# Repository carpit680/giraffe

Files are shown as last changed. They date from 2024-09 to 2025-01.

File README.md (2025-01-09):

<!-- @format -->

# _giraffe: a low-cost robotic manipulator_ 🦒

```text
                                   __             ___  ___
                            .-----|__.----.---.-.'  _.'  _.-----.
                            |  _  |  |   _|  _  |   _|   _|  -__|
                            |___  |__|__| |___._|__| |__| |_____|
                            |_____|

                               Why should fun be out of reach?
```

A [Koch v1.1](https://github.com/jess-moss/koch-v1-1) inspired even more cost-effective, ROS2-compatible, Open-Source robotic manipulator designed to lower the barriers of entry for Embodied AI and whatever else your robotic dreams may be.

To achieve these outcomes, we implemented the following significant changes:

## **Servo Selection**

We redesigned the arm around cost-efficient Waveshare servos replacing Dynamixel servos, effectively doubling the torque while reducing costs.

## **Design Enhancements**

- Adjusted the base design to transfer the radial load from the base motor to the supporting structure, reducing motor stress.
- Relocated the servo driver closer to the base for cleaner design.
- The servo mounts were redesigned to utilize the fasteners provided with the servos, minimizing the required assembly components to just the servos, 3D-printed parts, and a screwdriver.

- **[Teleop Tongs](https://github.com/carpit680/teleop_tongs) Integration**

  We integrated support for Teleop Tongs, another open-source project we built on top of [Dex Teleop](https://github.com/hello-robot/stretch_dex_teleop) (for the [Stretch 3](https://hello-robot.com/stretch-3-product) mobile manipulator by [Hello Robot](https://hello-robot.com/)), designed for teleoperating general-purpose robotic manipulators. This system features a 3D-printed tongs assembly equipped with multiple fiducial markers, serving as a stand-in for the end effector. This design enables intuitive and accessible control of the robotic arm.

  The motivation behind this integration was to offer a cost-effective, and user-friendly alternative to a leader & follower arm setup. By using Teleop Tongs, operators can manipulate the robotic arm naturally, simplifying teleoperation for applications in education, research, or DIY robotics projects.

---

## Assembly Instructions

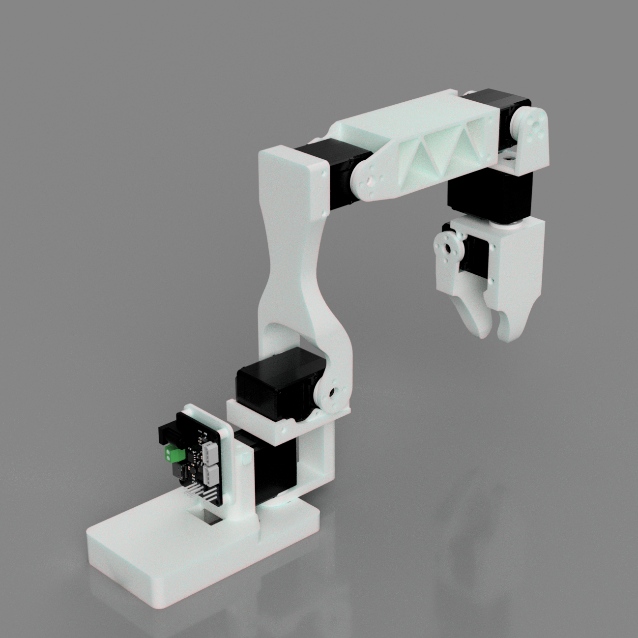
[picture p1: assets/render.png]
Image of Giraffe Rendered


### Sourcing Parts

Order the off the shelf parts for the arm using the links below.

| Part | Amount | Unit Cost (India)| Total Cost (India)| Buying Link (India) |
| --- | --- | --- | --- | --- |
| WaveShare ST3215 30Kg | 6 | ₹1,949.00 | ₹11,694.00 | [Robu.in](https://robu.in/product/waveshare-30kg-serial-bus-servo/) |
| Waveshare Serial Bus Servo Driver Board | 1 | ₹499.00 | ₹499.00 | [Robu.in](https://robu.in/product/waveshare-serial-bus-servo-driver-board-integrates-servo-power-supply-and-control-circuit-applicable-for-st-sc-series-serial-bus-servos/) |
| 12V 20A Power Supply | 1 | ₹895.00 | ₹895.00 | [Sharvi Electronics](https://sharvielectronics.com/product/12v-20a-smps-240w-dc-metal-power-supply-non-water-proof/) |
| Barrel Jack | 1 | ₹48.00 | ₹48.00 | [Robu.in](https://robu.in/product/90-degree-dc-5-52-1-wire/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) |
| Power cord | 1 | ₹95.00 | ₹95.00 | [Sharvi Electronics](https://sharvielectronics.com/product/3pin-250vac-6a-power-cord-with-open-ended-cable-1-8-meter/) |
| USB-C cable | 1 | ₹60.85 | ₹60.85 | [Sharvi Electronics](https://sharvielectronics.com/product/usb-2-0-a-type-male-usb-to-c-type-male-usb-cable-white-1-meter/) |
| Table clamp | 1 | ₹349.00 | ₹349.00 | [Amazon.in](https://www.amazon.in/Homdum%C2%AE-Heavy-Clamp-Clamping-Pieces/dp/B081JYTMMG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) |
| Total | | | ₹14,490 | |

### Printing The Parts

A variety of 3D printers can be used to print the necessary parts for the arm. Follow these steps for optimal printing results.

#### 1. Select A Printer

When choosing a printer, keep the following recommended specifications in mind. While other printers may work, these spececifications are a good starting point:

- **Layer Height:** Minimum 0.2mm
- **Material:** PLA+, ABS, PETG, or other durable plastics
- **Nozzle Diameter:** Maximum 0.4mm
- **Infill Density:** Approximately 30%
- **Suggested Printers:** Prusa Mini+, Bambu P1, Ender3, and similar models

#### 2. Prepare The Printer

- **Materials Needed:**

  - Standard Glue Stick
  - Putty Knife

- **Setup and Printing Process:**
  1. Calibrate the printer and level the print bed following your printer’s specific instructions.
  2. Clean the print bed, removing any dust or grease. If you use water or other cleaning agents, ensure the bed is fully dry.
  3. Apply a thin, even layer of glue to the print area. Avoid uneven application or clumps.
  4. Load the printer filament according to the printer's guidelines.
  5. Adjust the printer settings to match the recommended specifications listed above.
  6. Verify the file format, select files from the hardware folder, and begin printing.

#### 3. Print The Parts

Print one of each part found in `CAD/STL`

> List of Parts:
>
> - base_retainer
> - base
> - driver_mount
> - elbow
> - gripper
> - shoulder_lift
> - shoulder_pan
> - wrist_1
> - wrist_2

#### 4. Take Down

- After the print is done, use the putty knife to scrape the the parts off the print bed.
- Remove any support material from parts.

### Assembling The Parts

Construct the arms using this Assembly [Video](https://www.youtube.com/watch?v=8nQIg9BwwTk&t=8m20s) (Note: Follow the assembly instructions provided for Follower Arm starting at 08:20 of the video). After you assemble the arms from the video, power the arm using the 12V power supply. In addition, plug the arm into your computer using a USB-C cable.

The Arm after assembly should look like this:

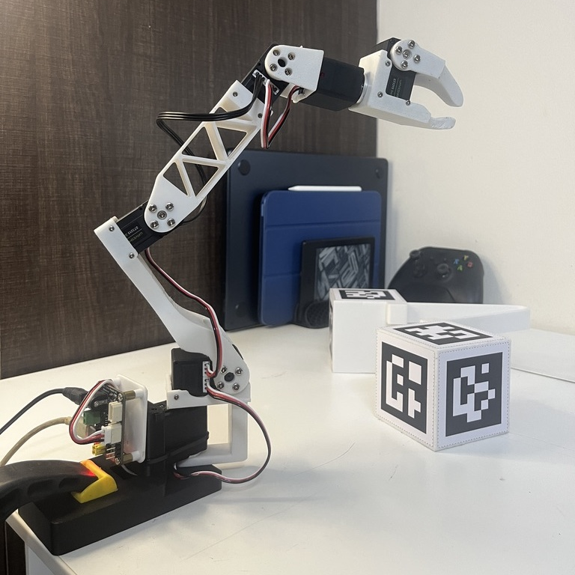
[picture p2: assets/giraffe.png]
Image of Giraffe


---

## Hardware Setup Instructions

> NOTE: Configurator and the rest of the high-level software stack is presently only compatible with Python.

### Clone The [giraffe](https://github.com/carpit680/giraffe) Repository

```bash
git clone https://github.com/carpit680/giraffe.git
cd giraffe
```

### Install Dependencies

```bash
pip install -r requirements.txt
pip install .
```

### Setup Permissions

```bash
sudo usermod -a -G dialout $USER
sudo newgrp dialout
```

### Setup Servo IDs

Use the configurator script in `scripts/` directory

```bash
python3 scripts/st_configurator.py
```
## Optional ROS2 Docker Development Environment Setup

Follow the instructions given here to set up a ROS2 Docker development environment: [ros2_docker_env](https://github.com/carpit680/ros2_docker_env)

## ROS2 Worksapce Setup

1. Install ROS2 Humble following these [installation instructions](https://docs.ros.org/en/humble/Installation.html).
2. Install Gazebo Ignition Fortress(LTS) following these [instructions](https://gazebosim.org/docs/fortress/install_ubuntu/).
3. Install Moveit 2

   ```bash
   # Install MoveIt 2 for ROS 2 Humble
   sudo apt update
   sudo apt install -y ros-humble-moveit
   ```

4. Install other dependencies

   ```bash
   sudo apt install -y ros-humble-ros2-control ros-humble-ros2-controllers
   sudo apt install -y python3-colcon-common-extensions python3-rosdep
   ```

5. Set Up giraffe_ws

   ```bash
   # Clone giraffe repository if you have not done so already

   # Update dependencies using rosdep
   cd <path-to-giraffe-repo>/giraffe_ws
   sudo rosdep init  # Only if not already initialized
   rosdep update
   rosdep install --from-paths src --ignore-src -r -y
   ```

6. Build and source the workspace

   ```bash
   cd <path-to-giraffe-repo>/giraffe_ws
   colcon build --symlink-install

   source install/local_setup.zsh
   # OR
   source install/local_setup.bash
   ```

## ROS2 Workspace Description
[giraffe_moveit_sim.webm](https://github.com/user-attachments/assets/942947e6-a5ca-4b55-a39b-d64a580de182)

### giraffe_description

This package contains URDF for _giraffe_ robotic manipulator along with ros2 control xacro, ros2 controller config files, and the launch files for the entire workspace.

- _display.launch.py_: This launch file visualizes the giraffe robot model in ROS 2. It includes:

  1. Robot State Publisher: Publishes the robot's state using the URDF.
  2. Joint State Publisher GUI: Enables interactive joint control.
  3. RViz Visualization: Displays the robot in a pre-configured RViz environment.

  _Usage_:

  ```bash
  ros2 launch giraffe_description display.launch.py
  ```

- _simulation.launch.py_: This launch file sets up the simulation environment for the giraffe robot in Gazebo and RViz. It includes:

  1. Gazebo Simulation: Starts Gazebo server and client with the giraffe robot model.
  2. Robot Description and State Publisher: Publishes the robot's URDF and joint states.
  3. Controllers: Spawns and activates controllers for joint trajectory and gripper control.
  4. RViz Visualization: Displays the robot model and state in RViz.

  _Usage_:

  ```bash
  ros2 launch giraffe_description simulation.launch.py
  ```

- _moveit_sim.launch.py_: This launch file integrates the giraffe robot with Gazebo, MoveIt! 2, and RViz for advanced motion planning and control. Key features:

  1. Gazebo Integration:
      - Spawns the giraffe robot in Gazebo.
      - Configures ros2_control and joint controllers.
  2. MoveIt! 2 Motion Planning:
      - Loads MoveIt! 2 configurations (SRDF, kinematics, OMPL planning).
      - Starts the move_group node for motion planning and execution.
  3. RViz Visualization:
      - Launches RViz preconfigured for MoveIt! 2 to visualize and interact with the robot.

  _Usage_:

  ```bash
  ros2 launch giraffe_description moveit_sim.launch.py
  ```

- _moveit_hardware.launch.py_: This launch file configures and launches the giraffe robot simulation, integrating Gazebo, MoveIt! 2, and a hardware interface for motion control. Key features:

  1. Gazebo Simulation:
      - Spawns the giraffe robot in Gazebo with URDF and robot controllers.
      - Initializes ros2_control and joint broadcasters for simulation.
  2. MoveIt! 2 Motion Planning:
      - Loads MoveIt! 2 configurations (SRDF, kinematics, and OMPL planning).
      - Starts the move_group node for motion planning and trajectory execution.
  3. RViz Visualization:
      - Displays the robot's state and motion planning visualization using a preconfigured RViz setup.
  4. Hardware Interface:
      - Includes a node for the giraffe robot's hardware interface for integration with controllers.

  _Usage_:

  ```bash
  ros2 launch giraffe_description moveit_hardware.launch.py
  ```

### giraffe_moveit_config

The giraffe_moveit_config package provides the MoveIt! 2 configuration for the 5-DoF robotic arm named "Giraffe," designed for use with ROS 2 Humble. It includes essential files for motion planning and execution, such as:

- **URDF and SRDF**: Defines the robot's kinematic structure and semantic description.
- **Kinematics Configuration**: Specifies IK solvers for planning.
- **OMPL Planning Configuration**: Configures planning pipelines for trajectory generation.
- **Controller Configuration**: Integrates with ros2_control for real-time trajectory execution.
- **RViz Configuration**: Pre-configured visualization setup for MoveIt! 2.

This package is utilized by the **giraffe_description** package's launch file to enable simulation and motion planning for the Giraffe arm in Gazebo and MoveIt! 2 environments.

### giraffe_control
The giraffe_control package provides hardware-level control for the 5-DoF Giraffe robotic arm. It includes a ROS 2 node, giraffe_driver, and a corresponding launch file to facilitate communication between ROS 2 and the physical hardware.

#### Features

1. Giraffe Servo Driver (giraffe_driver):

   - Implements direct communication with the Giraffe arm's servos using the Feetech motor bus.
   - Processes incoming command messages to set motor positions.
   - Read motor position feedback from the servos to publish feedback.
   - Supports homing offsets, acceleration settings, and position conversion from radians to motor steps.
   - Subscribes to /command for joint commands and publishes feedback to /feedback topic.
   - Interfaces with six motors:
     - base_link_shoulder_pan_joint
     - shoulder_pan_shoulder_lift_joint
     - shoulder_lift_elbow_joint
     - elbow_wrist_1_joint
     - wrist_1_wrist_2_joint
     - wrist_2_gripper_joint

2. Launch File:
   - Starts the giraffe_driver node.
   - Configures parameters for easy integration with other ROS 2 packages.

_Usage_:

The giraffe_control package is used by the giraffe_description package's launch file to provide hardware control during simulations and real-world operation. It ensures seamless integration of the Giraffe robotic arm into ROS 2 for both motion execution and feedback.

### giraffe_hardware
The giraffe_hardware package provides a ros2_control hardware interface for the Giraffe 5-DoF robotic arm plus a gripper joint. This interface lets you control and monitor the arm through standard ROS 2 controllers and topics, simplifying integration with motion planning frameworks like MoveIt.

#### Features:

1. Giraffe Hardware Interface (GiraffeInterface):
   - Implements a hardware_interface::SystemInterface plugin.
   - Subscribes to feedback (sensor_msgs/msg/JointState) for joint position updates.
   - Publishes to command (sensor_msgs/msg/JointState) to send joint commands.
   - Handles all six joints of the arm.

_Usage_:

- Integrate with controller_manager and standard controllers (e.g., joint_trajectory_controller).
- Place giraffe_interface in your ros2_control configuration.
- Commands and feedback are exchanged via standard ROS topics, enabling easy simulation or real hardware operation.

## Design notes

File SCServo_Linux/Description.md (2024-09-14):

### **Communication Layer:** SCS  

### **Hardware Interface Layer:** SCSerial  

**Application Layer:** SMSBL, SMSCL, and SCSCL correspond to the three series of servos.  
**Application Layer:** SMS_STS is compatible with the SMS/STS series servos.

```cpp
SMSBL sm;  // Define SMSBL series servo
SMSCL sm;  // Define SMSCL series servo
SCSCL sc;  // Define SCSCL series servo
SMS_STS sm_st;  // Define SMS/STS series servo
```

The interfaces for SMSCL, SMSBL, SCSCL, and SMS_STS are referenced in their respective header files.

- **INST.h** - Instruction definition header file  
- **SCS.h/SCS.cpp** - Communication layer program  
- **SCSerial.h/SCSerial.cpp** - Hardware interface program  
- **SMSBL.h/SMSBL.cpp** - SMSBL application layer program  
- **SMSCL.h/SMSCL.cpp** - SMSCL application layer program  
- **SCSCL.h/SCSCL.cpp** - SCSCL application layer program  
- **SMS_STS.h/SMS_STS.cpp** - SMS/STS application layer program  

(The memory table definitions are in the application layer header files SMSBL.h, SMSCL.h, SCSCL.h, and SMS_STS.h. The memory table definitions vary between different servo series.)

### Class Structure

```plaintext
                SMSBL class
SCS class <---  SCSerial class <--- SMSCL class
                SCSCL class
                SMS_STS class
```

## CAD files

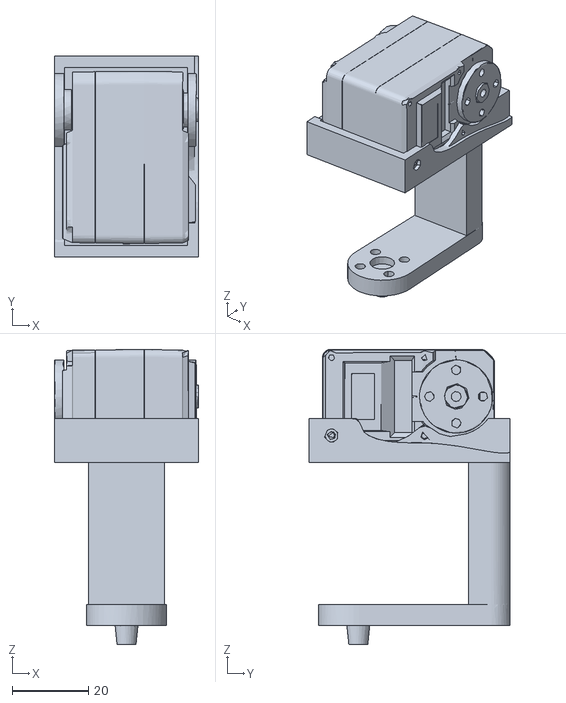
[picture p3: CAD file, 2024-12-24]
CAD/mujoco/giraffe_meshes/shoulder_pan_collision.stl
37.9 x 52.9 x 77.5

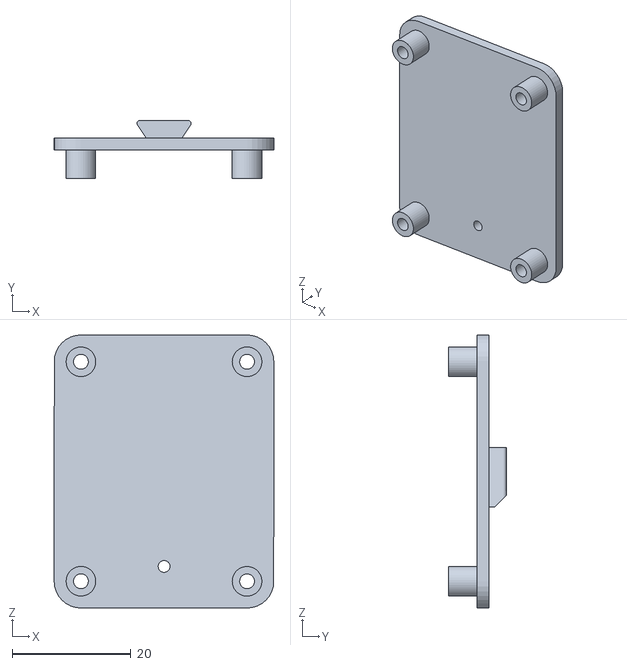
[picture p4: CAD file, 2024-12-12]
CAD/STL/driver_mount.stl
37.0 x 9.80 x 46.0

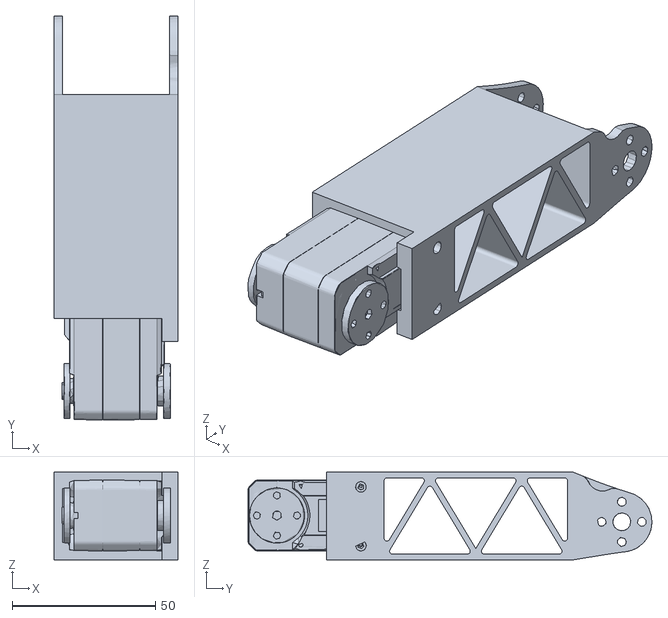
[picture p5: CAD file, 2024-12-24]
CAD/mujoco/giraffe_meshes/elbow_collision.stl
43.2 x 140.9 x 30.6

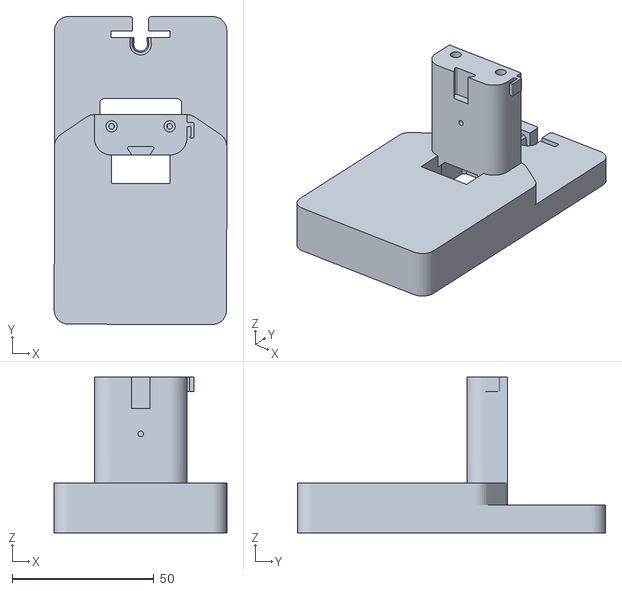
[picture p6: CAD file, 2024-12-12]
CAD/STL/base.stl
61.0 x 108.8 x 55.0

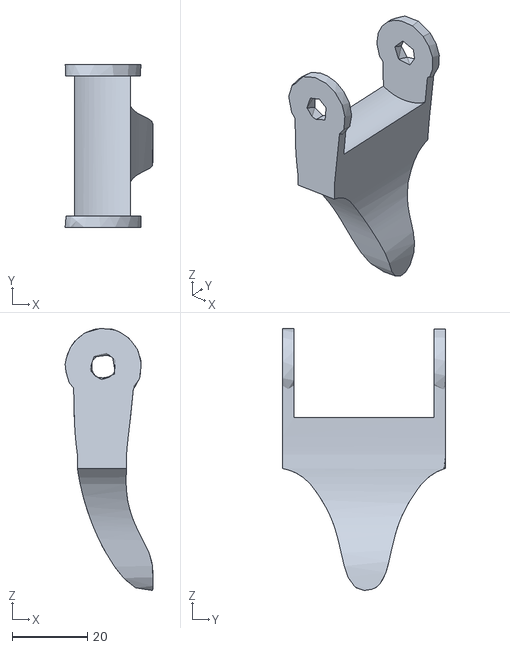
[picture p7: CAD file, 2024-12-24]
CAD/mujoco/giraffe_meshes/gripper_collision.stl
23.3 x 43.2 x 69.5

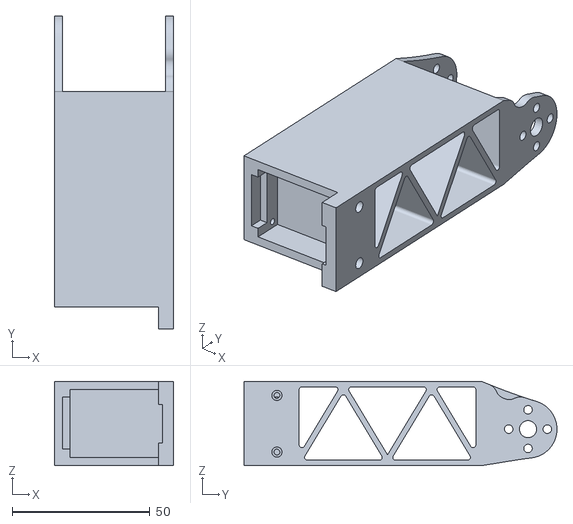
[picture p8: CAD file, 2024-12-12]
CAD/STL/elbow.stl
43.2 x 113.4 x 30.6

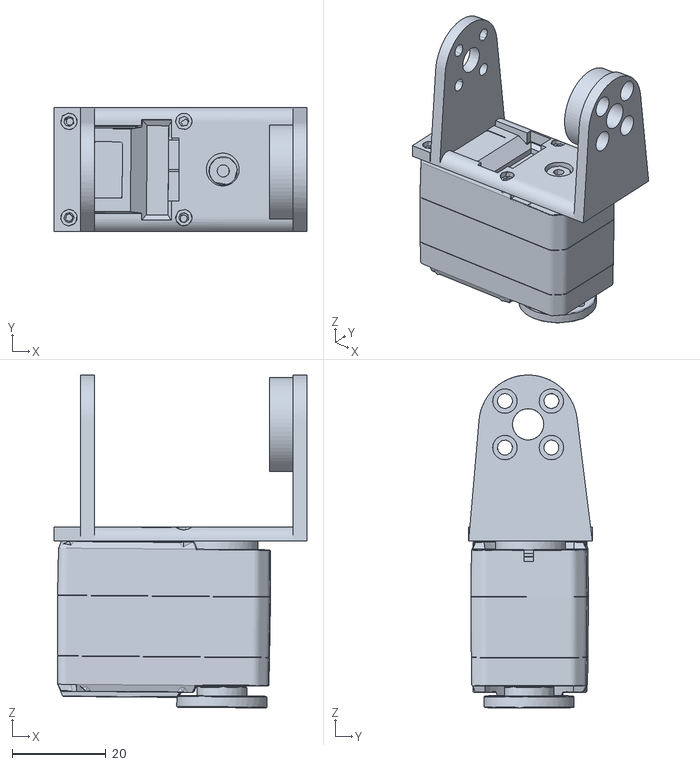
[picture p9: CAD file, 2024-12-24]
CAD/mujoco/giraffe_meshes/wrist_1_collision.stl
53.9 x 26.4 x 70.9

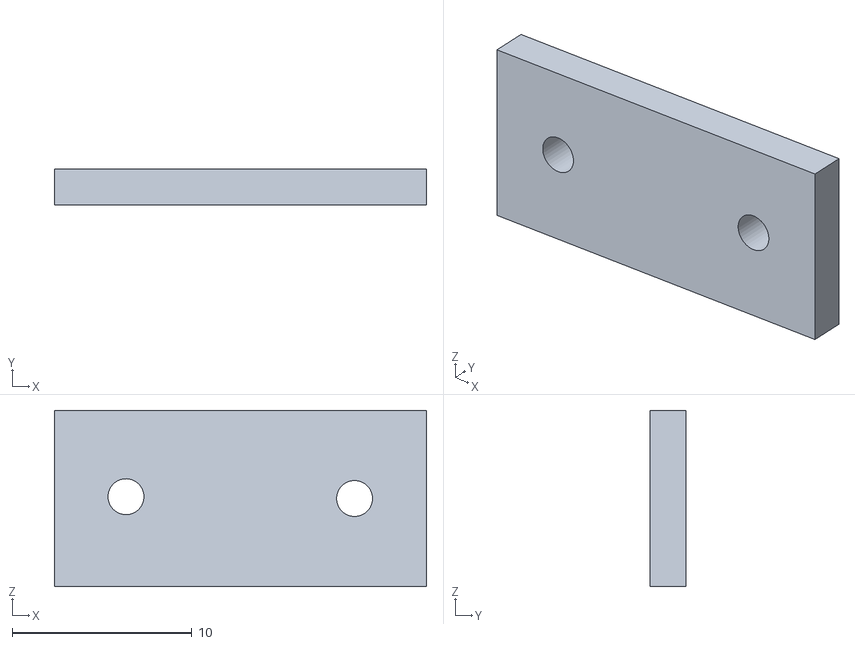
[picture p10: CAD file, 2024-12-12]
CAD/STL/base_retainer.stl
20.7 x 2.00 x 9.80

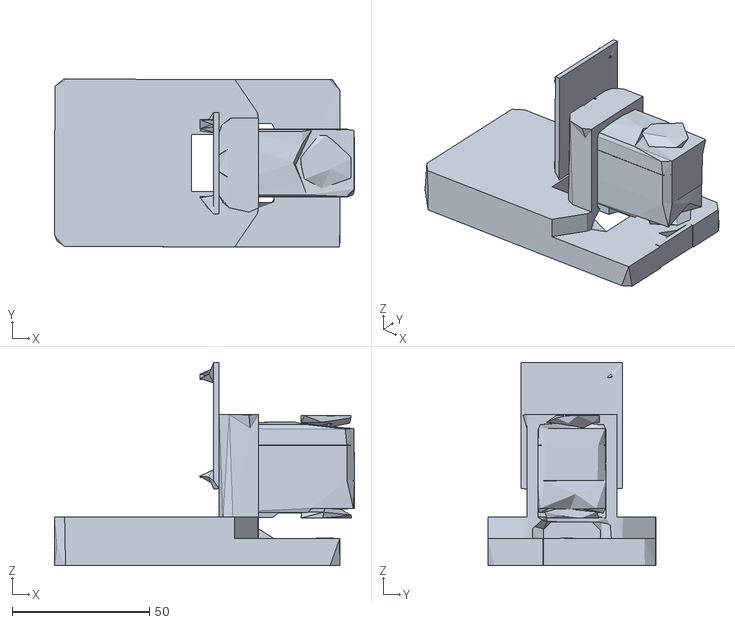
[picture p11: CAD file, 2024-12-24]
CAD/mujoco/giraffe_meshes/base_link_collision.stl
109.1 x 61.0 x 73.9

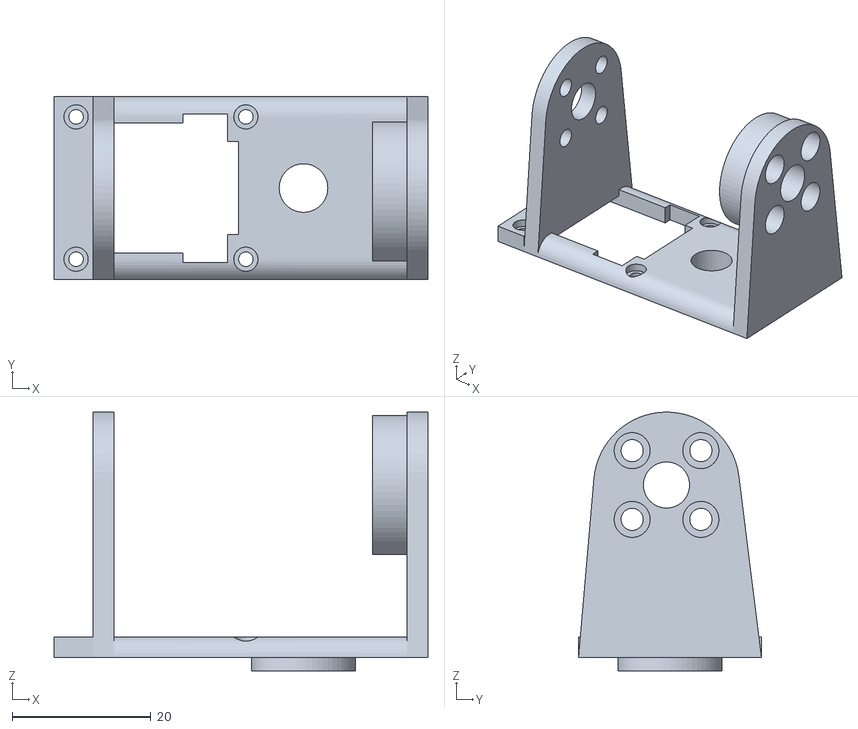
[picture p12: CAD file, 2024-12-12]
CAD/STL/wrist_1.stl
53.9 x 26.4 x 37.3

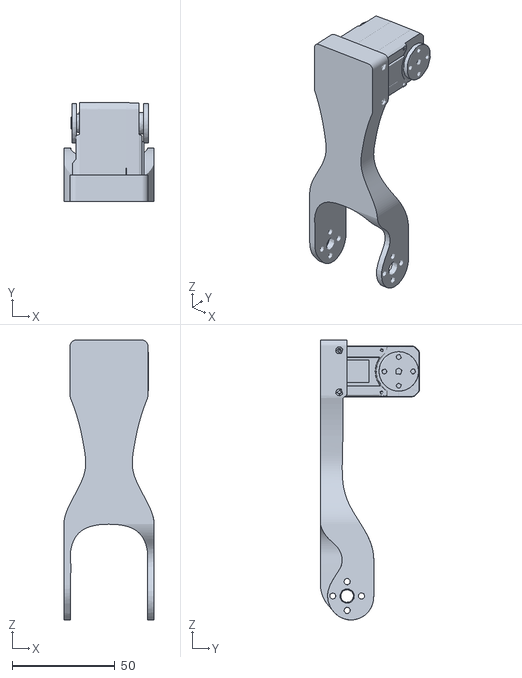
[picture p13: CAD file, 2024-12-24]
CAD/mujoco/giraffe_meshes/shoulder_lift_collision.stl
44.0 x 48.3 x 136.5

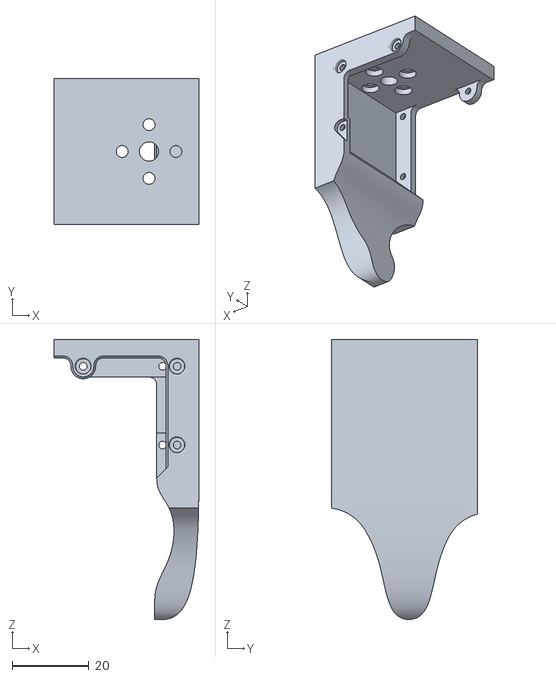
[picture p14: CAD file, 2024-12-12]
CAD/STL/wrist_2.stl
37.8 x 38.0 x 73.0

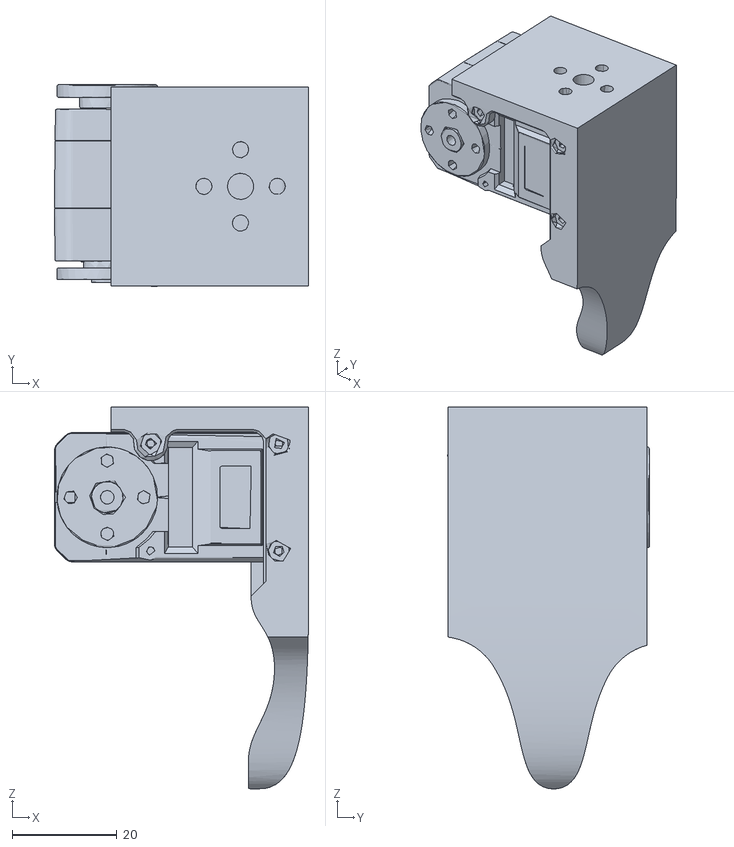
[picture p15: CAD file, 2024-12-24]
CAD/mujoco/giraffe_meshes/wrist_2_collision.stl
48.6 x 38.5 x 73.0

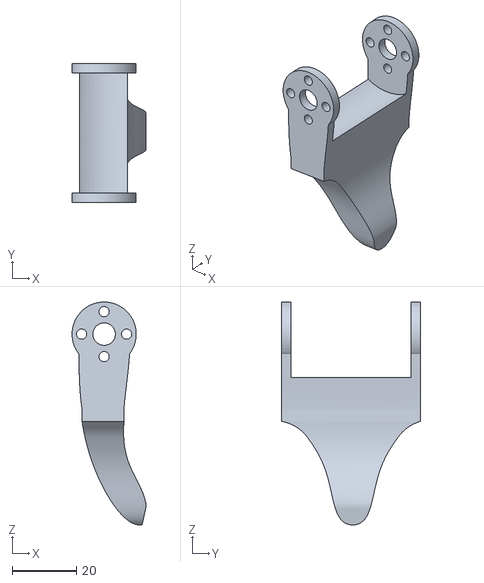
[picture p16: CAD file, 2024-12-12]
CAD/STL/gripper.stl
23.0 x 43.2 x 69.4

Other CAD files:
CAD/mujoco/giraffe_meshes/wrist_2.stl
CAD/STL/shoulder_pan.stl
CAD/mujoco/giraffe_meshes/wrist_1.stl
CAD/STL/shoulder_lift.stl
CAD/mujoco/giraffe_meshes/base_link.stl
CAD/mujoco/giraffe_meshes/elbow.stl
CAD/mujoco/giraffe_meshes/gripper.stl
CAD/mujoco/giraffe_meshes/shoulder_lift.stl
CAD/mujoco/giraffe_meshes/shoulder_pan.stl

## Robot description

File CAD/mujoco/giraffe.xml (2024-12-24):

<mujoco model="giraffe">
  <compiler angle="radian" meshdir="./giraffe_meshes/"/>

  <option timestep="0.001" impratio="100" integrator="implicitfast" cone="elliptic"/>

  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

  <statistic extent="0.6" center="0 0 0.1"/>

  <default class="main">
    <default class="giraffe">
      <joint actuatorfrcrange="-10 10" armature="0.1" damping="1"/>
      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
      <general biastype="affine" gainprm="1000" biasprm="0 -1000 -10"/>
      <default class="visual">
        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
      </default>
      <default class="collision">
        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
        <default class="gripper">
          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
        </default>
      </default>
    </default>
  </default>

  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

  <worldbody>
    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
    <camera name="camera_front" pos="0.049 0.5 0.225" quat="0.0228997 0.0161522 0.576165 0.816853"/>
    <camera name="camera_top" pos="0 0.1 0.6"/>
    <camera name="camera_vizu" pos="-0.1 0.6 0.3" quat="-0.127114 -0.0847427 0.508456 0.847427"/>
    <light pos="0 0 3" dir="0 0 -1"/>

    <body name="base_link" childclass="giraffe" quat="0.707105 0 0 0.707108">
      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

      <body name="shoulder_pan" pos="0.000132673 0.09892 0.05455" quat="0.707374 0 0 0.70684">
        <inertial pos="0.018989 0.000179472 -0.00571101" quat="0.69328 -0.134099 -0.12915 0.696205" mass="0.250234" diaginertia="0.00016813 0.000134257 7.53191e-05"/>
        <joint name="base_link_shoulder_pan_joint" pos="0 0 0" axis="0 0 1" range="-1.8326 1.8326"/>
        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

        <body name="shoulder_lift" pos="0.0257194 0.0189447 0.0173761" quat="0.49981 0.49981 -0.50019 -0.50019">
          <inertial pos="0.0184018 0.0676401 0.00245879" quat="0.52592 0.496227 -0.485468 0.491413" mass="0.344051" diaginertia="0.000487169 0.000468958 8.53578e-05"/>
          <joint name="shoulder_pan_shoulder_lift_joint" pos="0 0 0" axis="-1 2.06744e-10 0.000758654" range="-0.785398 1.65806"/>
          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

          <body name="elbow" pos="0.0378935 0.109491 -0.0251964" quat="0 1 -1.6564e-10 0">
            <inertial pos="-0.0191099 -0.00194784 0.062378" quat="0.708777 -0.00565854 -0.0109736 0.705325" mass="0.340735" diaginertia="0.000442489 0.000417467 9.60818e-05"/>
            <joint name="shoulder_lift_elbow_joint" pos="0 0 0" axis="1 -1.24536e-10 -3.45629e-07" range="-1.53589 1.78024"/>
            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

            <body name="wrist_1" pos="-0.0376163 -0.00221579 0.12026" quat="1 0 0 -1.23824e-10">
              <inertial pos="0.0195541 -0.0003021 0.0267688" quat="0.655112 -0.26413 -0.267553 0.655347" mass="0.115855" diaginertia="7.00665e-05 4.95009e-05 3.1834e-05"/>
              <joint name="elbow_wrist_1_joint" pos="0 0 0" axis="-1 -1.23112e-10 0.000758346" range="-1.79769 1.79769"/>
              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

              <body name="wrist_2" pos="0.0271658 -0.00019892 0.060318" quat="0.498153 -0.502218 0.501864 0.497749">
                <inertial pos="-0.0223517 -0.000399723 -0.00128848" quat="0.396826 0.566256 0.626577 0.359562" mass="0.204797" diaginertia="0.00010478 0.00010171 4.79067e-05"/>
                <joint name="wrist_1_wrist_2_joint" pos="0 0 0" axis="-0.999945 0.006662 -0.00813227" range="-3.14159 3.14159"/>
                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

                <body name="gripper" pos="-0.0171717 -0.0193104 -0.0255795" quat="0.707083 -0.707119 -0.00315993 -0.00262362">
                  <inertial pos="-0.0250961 -0.00522173 0.0186077" quat="0.428458 0.407091 0.554617 0.585748" mass="0.127948" diaginertia="4.32473e-05 2.6861e-05 2.09207e-05"/>
                  <joint name="wrist_2_gripper_joint" pos="0 0 0" axis="-0.00742063 -0.000759 -0.999972" range="0 1.5708"/>
                  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
                </body>
              </body>
            </body>
          </body>
        </body>
      </body>
    </body>

    <body name="cube" pos="0 0.2 0.01">
      <inertial pos="0 0 0" mass="10" diaginertia="0.00016667 0.00016667 0.00016667"/>
      <joint name="red_box_joint" type="free" limited="false" actuatorfrclimited="false"/>
      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
    </body>
  </worldbody>

  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

  <actuator>
    <general name="base_link_shoulder_pan_joint" class="giraffe" joint="base_link_shoulder_pan_joint" ctrlrange="-1.8326 1.8326"/>
    <general name="shoulder_pan_shoulder_lift_joint" class="giraffe" joint="shoulder_pan_shoulder_lift_joint" ctrlrange="-0.785398 1.65806"/>
    <general name="shoulder_lift_elbow_joint" class="giraffe" joint="shoulder_lift_elbow_joint" ctrlrange="-1.53589 1.78024"/>
    <general name="elbow_wrist_1_joint" class="giraffe" joint="elbow_wrist_1_joint" ctrlrange="-1.79769 1.79769"/>
    <general name="wrist_1_wrist_2_joint" class="giraffe" joint="wrist_1_wrist_2_joint" ctrlrange="-3.14159 3.14159"/>
    <general name="wrist_2_gripper_joint" class="giraffe" joint="wrist_2_gripper_joint" ctrlrange="0 1.5708"/>
  </actuator>
</mujoco>

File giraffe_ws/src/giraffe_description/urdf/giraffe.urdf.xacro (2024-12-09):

<?xml version='1.0' encoding='utf-8'?>
<robot xmlns:xacro="http://www.ros.org/wiki/xacro" name="giraffe">

    <xacro:include filename="$(find giraffe_description)/urdf/giraffe_ros2_control.xacro" />
    <xacro:giraffe_ros2_control />

    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

    <link name="world"></link>
    <link name="gripper">
        <inertial>
            <origin xyz="-0.025096114457859146 -0.0052217339196567285 0.018607684265278243" rpy="0.0 -1.9697037091450396e-29 -2.465190328815662e-32" />
            <mass value="0.12794799500230522" />
            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
        </inertial>
        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
    </link>
    <link name="wrist_2">
        <inertial>
            <origin xyz="-0.02235167904590888 -0.00039972306754894717 -0.0012884800639650607" rpy="0.0 -0.0 0.0" />
            <mass value="0.20479740953235442" />
            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
        </inertial>
        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
    </link>
    <link name="wrist_1">
        <inertial>
            <origin xyz="0.01955407720307944 -0.00030209951905803224 0.026768801085658007" rpy="0.0 -1.1498681155338425e-23 -2.584939414228212e-26" />
            <mass value="0.11585466541730399" />
            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
        </inertial>
        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
    </link>
    <link name="elbow">
        <inertial>
            <origin xyz="-0.019109899420648016 -0.0019478420126233331 0.062377972599983254" rpy="0.0 -1.1766070558741976e-23 0.0" />
            <mass value="0.3407348467366932" />
            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
        </inertial>
        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
    </link>
    <link name="shoulder_lift">
        <inertial>
            <origin xyz="0.018401845016294084 0.06764007255137808 0.0024587901675857007" rpy="-2.5243548967072383e-29 3.2427363422303987e-23 2.584939414228212e-26" />
            <mass value="0.34405090664671173" />
            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
        </inertial>
        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
    </link>
    <link name="shoulder_pan">
        <inertial>
            <origin xyz="0.018989018317661446 0.00017947215105527215 -0.005711008429640101" rpy="3.944304526105059e-31 -0.0 -1.1697403604428189e-46" />
            <mass value="0.2502336197461597" />
            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
        </inertial>
        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
    </link>
    <link name="base_link">
        <inertial>
            <origin xyz="0.04880840731253524 -0.00010333124781364511 0.013957019259335951" rpy="0.0 0.0 0.0" />
            <mass value="0.8122108919622869" />
            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
        </inertial>
        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
    </link>

    <joint name="world_joint" type="fixed">
        <parent link="world" />
        <child link="base_link" />
        <origin xyz="0.0 0.0 0.0" rpy="0 0 1.5708" />
    </joint>
    <joint name="base_link_shoulder_pan_joint" type="revolute">
        <origin xyz="0.09891995753862716 -0.00013303607482287617 0.05455000000000001" rpy="3.189786117866041e-15 3.393805650568627e-16 -0.0007586542251351899" />
        <parent link="base_link" />
        <child link="shoulder_pan" />
        <axis xyz="-4.930380657631324e-32 2.37251531204244e-15 1.0" />
        <limit lower="-1.832596" upper="1.832596" effort="1000000" velocity="1000000" />
    </joint>
    <joint name="shoulder_pan_shoulder_lift_joint" type="revolute">
        <origin xyz="0.02571940999999997 0.018944660000000037 0.017376069999999952" rpy="1.5707963267950535 -2.0674681179012968e-10 -1.5715549810200329" />
        <parent link="shoulder_pan" />
        <child link="shoulder_lift" />
        <axis xyz="-0.9999997122218972 2.0674449877203995e-10 0.0007586541523615138" />
        <limit lower="-0.785398" upper="1.658063" effort="1000000" velocity="1000000" />
    </joint>
    <joint name="shoulder_lift_elbow_joint" type="revolute">
        <origin xyz="0.037893485547286214 0.10949145999216181 -0.025196435301140276" rpy="3.1415926535895418 2.265006756586156e-14 -3.3128010369466755e-10" />
        <parent link="shoulder_lift" />
        <child link="elbow" />
        <axis xyz="1.0000002880403989 -1.245357002578147e-10 -3.456292375562768e-07" />
        <limit lower="-1.53589" upper="1.780236" effort="1000000" velocity="1000000" />
    </joint>
    <joint name="elbow_wrist_1_joint" type="revolute">
        <origin xyz="-0.03761630670794674 -0.0022157899953267803 0.12026017684096592" rpy="1.8787933722333255e-13 2.512616851854867e-14 -2.476481313343611e-10" />
        <parent link="elbow" />
        <child link="wrist_1" />
        <axis xyz="-0.9999998631005341 -1.23112379231774e-10 0.0007583461697307804" />
        <limit lower="-1.797689" upper="1.797689" effort="1000000" velocity="1000000" />
    </joint>
    <joint name="wrist_1_wrist_2_joint" type="revolute">
        <origin xyz="0.027165827341760113 -0.00019891999664992 0.06031796682590525" rpy="-3.049102007927164 1.5625820319968764 -1.4783560893203032" />
        <parent link="wrist_1" />
        <child link="wrist_2" />
        <axis xyz="-0.9999449329225374 0.006662002215913354 -0.008132268196377131" />
        <limit lower="-3.141593" upper="3.141593" effort="1000000" velocity="1000000" />
    </joint>
    <joint name="wrist_2_gripper_joint" type="revolute">
        <origin xyz="-0.017171676526959914 -0.019310353391698003 -0.025579471562416883" rpy="-1.5708498378135036 -0.0081791843801793 0.0007586796016247204" />
        <parent link="wrist_2" />
        <child link="gripper" />
        <axis xyz="-0.007420635544791429 -0.0007590000001611277 -0.9999726580742655" />
        <limit lower="0.0" upper="1.570796" effort="1000000" velocity="1000000" />
    </joint>

    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
    
</robot>

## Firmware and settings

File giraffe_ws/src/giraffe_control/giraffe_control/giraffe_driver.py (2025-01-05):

#!/usr/bin/env python3
import rclpy
from rclpy.node import Node
from sensor_msgs.msg import JointState
from trajectory_msgs.msg import JointTrajectory, JointTrajectoryPoint
from giraffe_control.feetech import FeetechMotorsBus
import numpy as np

class GiraffeDriver(Node):

    def __init__(self):
        super().__init__("giraffe_driver")
        example_param = self.declare_parameter("example_param", "default_value").value
        self.get_logger().info(f"Declared parameter 'example_param'. Value: {example_param}")

        self.motors_bus = FeetechMotorsBus(
            port="/dev/ttyACM0",
            motors={
                "base_link_shoulder_pan_joint": (1, "sts3215"),
                "shoulder_pan_shoulder_lift_joint": (2, "sts3215"),
                "shoulder_lift_elbow_joint": (3, "sts3215"),
                "elbow_wrist_1_joint": (4, "sts3215"),
                "wrist_1_wrist_2_joint": (5, "sts3215"),
                "wrist_2_gripper_joint": (6, "sts3215"),
            },
        )
        self.motor_order = [
            "base_link_shoulder_pan_joint",
            "shoulder_pan_shoulder_lift_joint",
            "shoulder_lift_elbow_joint",
            "elbow_wrist_1_joint",
            "wrist_1_wrist_2_joint",
            "wrist_2_gripper_joint",
        ]
        self.motors_bus.connect()

        # ROS topics
        self.joint_state_pub = self.create_publisher(JointState, "/feedback", 10)
        self.joint_command_sub = self.create_subscription(
            JointState, "/command", self.joint_state_callback, 10
        )


        # Timer for publishing joint states
        self.timer = self.create_timer(0.01, self.publish_joint_states)

        # Homing offsets
        self.offsets = [3.223, 3.043, 2.979, 3.152, 3.1415, 4.9532]
        self.set_motor_acceleration(5, 50)
    
    def joint_state_callback(self, msg: JointState):
        """
        Callback for processing incoming JointState messages and writing positions and velocities to servos.
        """
        positions = []

        homing_offsets = [-2082, -1992, -1949, -2023, -2046, -3225]
        for motor_name, offset in zip(self.motors_bus.motor_names, homing_offsets):
            if motor_name in msg.name:
                idx = msg.name.index(motor_name)
                try:
                    # Convert position to steps
                    radians = msg.position[idx]
                    model = self.motors_bus.motors[motor_name][1]
                    step_value = self.radians_to_steps(-radians, model) - offset
                    positions.append(step_value)


                except Exception as e:
                    self.get_logger().warn(f"Failed to process joint {motor_name}: {e}")
                    positions.append(0)
            else:
                positions.append(0)

        # Write all positions and velocities
        self.motors_bus.write("Goal_Position", np.array(positions), self.motor_order)

        # self.get_logger().info(f"Set positions: {positions}")

    def publish_joint_states(self):
        joint_state = JointState()
        joint_state.header.stamp = self.get_clock().now().to_msg()
        joint_state.name = self.motor_order
        positions = self.motors_bus.read("Present_Position", self.motor_order)
        position_radians = self.motors_bus.steps_to_radians(positions, self.motors_bus.motors[self.motor_order[0]][1])
        for position, offset in zip(position_radians, self.offsets):
            joint_state.position.append(-position + offset)
        # TODO: Test velocity and effort before using them in state interface. Also add velocity and effort state interfaces to the controller.
        # joint_state.velocity = self.motors_bus.read("Present_Speed", self.motor_order)
        # joint_state.effort = self.motors_bus.read("Present_Load", self.motor_order)
        self.joint_state_pub.publish(joint_state)

    def set_motor_acceleration(self, acceleration: int, gripper_acceleration: int):
        """Set acceleration for all motors."""
        try:
            motor_names = self.motors_bus.motor_names
            non_gripper_motors = motor_names[:-1]
            accelerations = [acceleration] * len(non_gripper_motors)
            self.motors_bus.write("Acceleration", accelerations, non_gripper_motors)
            gripper = motor_names[-1]
            self.motors_bus.write("Acceleration", gripper_acceleration, gripper)
            self.get_logger().info(f"Set acceleration to {acceleration} for {motor_names[:-1]}.")
            self.get_logger().info(f"Set acceleration to {gripper_acceleration} for {gripper}.")
        except Exception as e:
            self.get_logger().warn(f"Failed to set acceleration for motors: {e}")

    def radians_to_steps(self, radians: float, model: str) -> int:
        """
        Converts radians to motor steps based on the model resolution.
        Assumes a full rotation (-pi to +pi radians) maps to the full step range.
        """
        resolution = 4096  # Get resolution from model
        degrees = np.degrees(radians)  # Convert radians to degrees
        steps = int(degrees / 360.0 * resolution)  # Map degrees to steps
        return steps


def main(args=None):
    rclpy.init(args=args)

    giraffe_driver = GiraffeDriver()

    try:
        rclpy.spin(giraffe_driver)
    except KeyboardInterrupt:
        pass

    giraffe_driver.destroy_node()
    giraffe_driver.motors_bus.disconnect()
    rclpy.try_shutdown()


if __name__ == '__main__':
    main()

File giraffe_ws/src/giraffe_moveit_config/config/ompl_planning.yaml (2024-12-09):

planning_plugin: ompl_interface/OMPLPlanner
request_adapters: >-
  default_planner_request_adapters/AddTimeOptimalParameterization
  default_planner_request_adapters/ResolveConstraintFrames
  default_planner_request_adapters/FixWorkspaceBounds
  default_planner_request_adapters/FixStartStateBounds
  default_planner_request_adapters/FixStartStateCollision
  default_planner_request_adapters/FixStartStatePathConstraints
start_state_max_bounds_error: 0.1
planner_configs:
  SBLkConfigDefault:
    type: geometric::SBL
    range: 0.0  # Max motion added to tree. ==> maxDistance_ default: 0.0, if 0.0, set on setup()
  ESTkConfigDefault:
    type: geometric::EST
    range: 0.0  # Max motion added to tree. ==> maxDistance_ default: 0.0, if 0.0 setup()
    goal_bias: 0.05  # When close to goal select goal, with this probability. default: 0.05
  LBKPIECEkConfigDefault:
    type: geometric::LBKPIECE
    range: 0.0  # Max motion added to tree. ==> maxDistance_ default: 0.0, if 0.0, set on setup()
    border_fraction: 0.9  # Fraction of time focused on boarder default: 0.9
    min_valid_path_fraction: 0.5  # Accept partially valid moves above fraction. default: 0.5
  BKPIECEkConfigDefault:
    type: geometric::BKPIECE
    range: 0.0  # Max motion added to tree. ==> maxDistance_ default: 0.0, if 0.0, set on setup()
    border_fraction: 0.9  # Fraction of time focused on boarder default: 0.9
    failed_expansion_score_factor: 0.5  # When extending motion fails, scale score by factor. default: 0.5
    min_valid_path_fraction: 0.5  # Accept partially valid moves above fraction. default: 0.5
  KPIECEkConfigDefault:
    type: geometric::KPIECE
    range: 0.0  # Max motion added to tree. ==> maxDistance_ default: 0.0, if 0.0, set on setup()
    goal_bias: 0.05  # When close to goal select goal, with this probability. default: 0.05
    border_fraction: 0.9  # Fraction of time focused on boarder default: 0.9 (0.0,1.]
    failed_expansion_score_factor: 0.5  # When extending motion fails, scale score by factor. default: 0.5
    min_valid_path_fraction: 0.5  # Accept partially valid moves above fraction. default: 0.5
  RRTkConfigDefault:
    type: geometric::RRT
    range: 0.0  # Max motion added to tree. ==> maxDistance_ default: 0.0, if 0.0, set on setup()
    goal_bias: 0.05  # When close to goal select goal, with this probability? default: 0.05
  RRTConnectkConfigDefault:
    type: geometric::RRTConnect
    range: 0.0  # Max motion added to tree. ==> maxDistance_ default: 0.0, if 0.0, set on setup()
  RRTstarkConfigDefault:
    type: geometric::RRTstar
    range: 0.0  # Max motion added to tree. ==> maxDistance_ default: 0.0, if 0.0, set on setup()
    goal_bias: 0.05  # When close to goal select goal, with this probability? default: 0.05
    delay_collision_checking: 1  # Stop collision checking as soon as C-free parent found. default 1
  TRRTkConfigDefault:
    type: geometric::TRRT
    range: 0.0  # Max motion added to tree. ==> maxDistance_ default: 0.0, if 0.0, set on setup()
    goal_bias: 0.05  # When close to goal select goal, with this probability? default: 0.05
    max_states_failed: 10  # when to start increasing temp. default: 10
    temp_change_factor: 2.0  # how much to increase or decrease temp. default: 2.0
    min_temperature: 10e-10  # lower limit of temp change. default: 10e-10
    init_temperature: 10e-6  # initial temperature. default: 10e-6
    frountier_threshold: 0.0  # dist new state to nearest neighbor to disqualify as frontier. default: 0.0 set in setup()
    frountierNodeRatio: 0.1  # 1/10, or 1 nonfrontier for every 10 frontier. default: 0.1
    k_constant: 0.0  # value used to normalize expresssion. default: 0.0 set in setup()
  PRMkConfigDefault:
    type: geometric::PRM
    max_nearest_neighbors: 10  # use k nearest neighbors. default: 10
  PRMstarkConfigDefault:
    type: geometric::PRMstar
  FMTkConfigDefault:
    type: geometric::FMT
    num_samples: 1000  # number of states that the planner should sample. default: 1000
    radius_multiplier: 1.1  # multiplier used for the nearest neighbors search radius. default: 1.1
    nearest_k: 1  # use Knearest strategy. default: 1
    cache_cc: 1  # use collision checking cache. default: 1
    heuristics: 0  # activate cost to go heuristics. default: 0
    extended_fmt: 1  # activate the extended FMT*: adding new samples if planner does not finish successfully. default: 1
  BFMTkConfigDefault:
    type: geometric::BFMT
    num_samples: 1000  # number of states that the planner should sample. default: 1000
    radius_multiplier: 1.0  # multiplier used for the nearest neighbors search radius. default: 1.0
    nearest_k: 1  # use the Knearest strategy. default: 1
    balanced: 0  # exploration strategy: balanced true expands one tree every iteration. False will select the tree with lowest maximum cost to go. default: 1
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

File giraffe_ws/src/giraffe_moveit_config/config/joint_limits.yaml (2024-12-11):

# joint_limits.yaml allows the dynamics properties specified in the URDF to be overwritten or augmented as needed

# For beginners, we downscale velocity and acceleration limits.
# You can always specify higher scaling factors (<= 1.0) in your motion requests.  # Increase the values below to 1.0 to always move at maximum speed.
default_velocity_scaling_factor: 1.0
default_acceleration_scaling_factor: 1.0

# Specific joint properties can be changed with the keys [max_position, min_position, max_velocity, max_acceleration]
# Joint limits can be turned off with [has_velocity_limits, has_acceleration_limits]
joint_limits:
  base_link_shoulder_pan_joint:
    has_velocity_limits: true
    max_velocity: 1.0
    has_acceleration_limits: true
    max_acceleration: 1.0
  elbow_wrist_1_joint:
    has_velocity_limits: true
    max_velocity: 1.0
    has_acceleration_limits: true
    max_acceleration: 1.0
  shoulder_lift_elbow_joint:
    has_velocity_limits: true
    max_velocity: 1.0
    has_acceleration_limits: true
    max_acceleration: 1.0
  shoulder_pan_shoulder_lift_joint:
    has_velocity_limits: true
    max_velocity: 1.0
    has_acceleration_limits: true
    max_acceleration: 1.0
  wrist_1_wrist_2_joint:
    has_velocity_limits: true
    max_velocity: 1.0
    has_acceleration_limits: true
    max_acceleration: 1.0
  wrist_2_gripper_joint:
    has_velocity_limits: true
    max_velocity: 1.0
    has_acceleration_limits: true
    max_acceleration: 1.0

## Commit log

2024-09-14 added original python and cpp libs for linux
    [pyvenv.cfg]
2024-09-17 code restructuring
    [pyvenv.cfg]
2024-09-17 fixed relative paths for sdk usage
    [ping.py, read.py, read_write.py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]
2024-09-29 enabled changing servo ID
2024-09-29 fixed undefined scs_lobyte and hibyte bug
    [scscl.py]
2024-09-29 setting servo IDs for all servo functional
2024-10-06 added motor and robot configs
2024-10-08 Revert "restructuring"
    This reverts commit e83d0c2abc0298fc7dccb157dbf3f4a596ea0f90.
    [WritePos.cpp, ping.py, protocol_packet_handler.py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]
2024-10-08 reset st python code
    [ping.py, protocol_packet_handler.py, read.py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]
2024-11-30 added giraffe ros2 simulation pkg
    [base_link.stl, base_plate.STL, basement.STL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]
2024-12-09 init moveit setup
    [giraffe.ros2_control.xacro, giraffe.urdf.xacro, giraffe_controller.yaml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]
2024-12-09 moveit gazebo execution functional
    [giraffe.ros2_control.xacro, giraffe.urdf.xacro, giraffe_controller.yaml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]
2024-12-09 hardware moves rviz
    [giraffe_hardware.yaml]
2024-12-11 hardware and gazebo sim funct with moveit
    [giraffe.ros2_control.xacro, giraffe.urdf.xacro, giraffe_controller.yaml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]
2024-12-11 launch file cleanup and velocity and accel limits update
    [joint_limits.yaml]
2024-12-12 addet step, stl, images
    [base.stl, base_retainer.stl, driver_mount.stl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]
2024-12-12 updated readme with assembly instructions
2024-12-13 updated readme, updated directory structure for STL
    [base.stl, base_retainer.stl, driver_mount.stl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]
2024-12-14 changed subscription from joint_state to joint_trajectory
2024-12-14 separate accel for gripper servo
2024-12-15 Gazebo ignition switch for moveit.launch.py
    [giraffe.sdf, giraffe_ros2_control.xacro]
2024-12-15 fixed urdf location issue
2024-12-15 added ign ros2 control to xacro
    [giraffe.ros2_control.xacro, giraffe_ros2_control.xacro]
2024-12-16 sim without moveit funct
    [giraffe.xacro.urdf]
2024-12-16 switch back to joint_states for moving hardware
2024-12-17 hardware interface initial commit
    [giraffe_controller.yaml, giraffe_hardware.xacro.urdf]
2024-12-17 switched arduino to giraffe interface
    [giraffe_hardware.xacro.urdf]
2024-12-18 changed node name to giraffe_driver in giraffe_control pkg
    [giraffe_hardware.yaml]
2024-12-24 added Mujoco Compatible MJCF files
    [base_link.stl, base_link_collision.stl, elbow.stl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]
2025-01-05 cleanup and pid updates
    [giraffe.sdf, giraffe_controller.yaml, giraffe_hardware.yaml]
